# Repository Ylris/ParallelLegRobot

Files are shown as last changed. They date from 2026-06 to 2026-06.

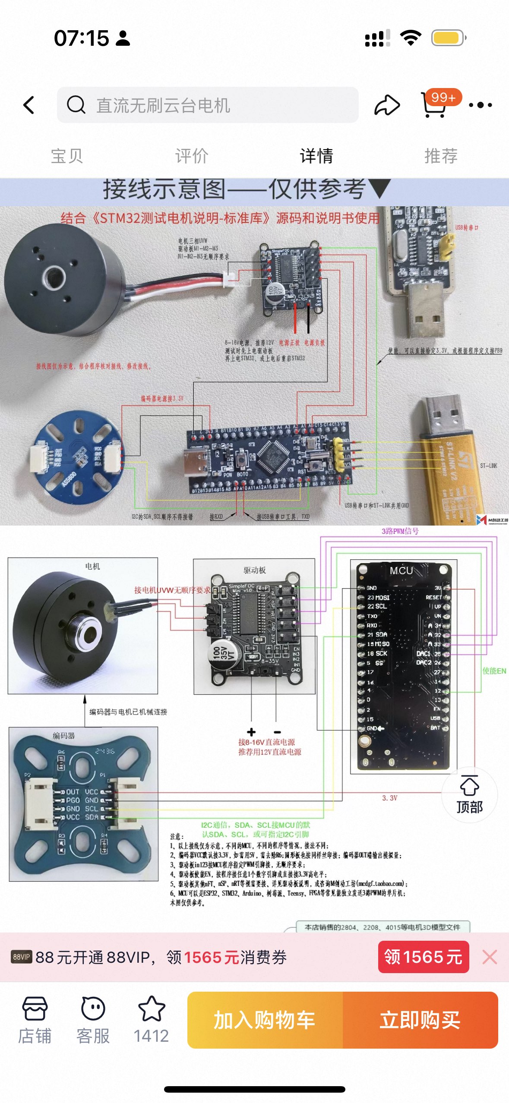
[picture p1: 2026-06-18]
docs/3ED894091CCDE273470E72D72C9ACDA5.jpg

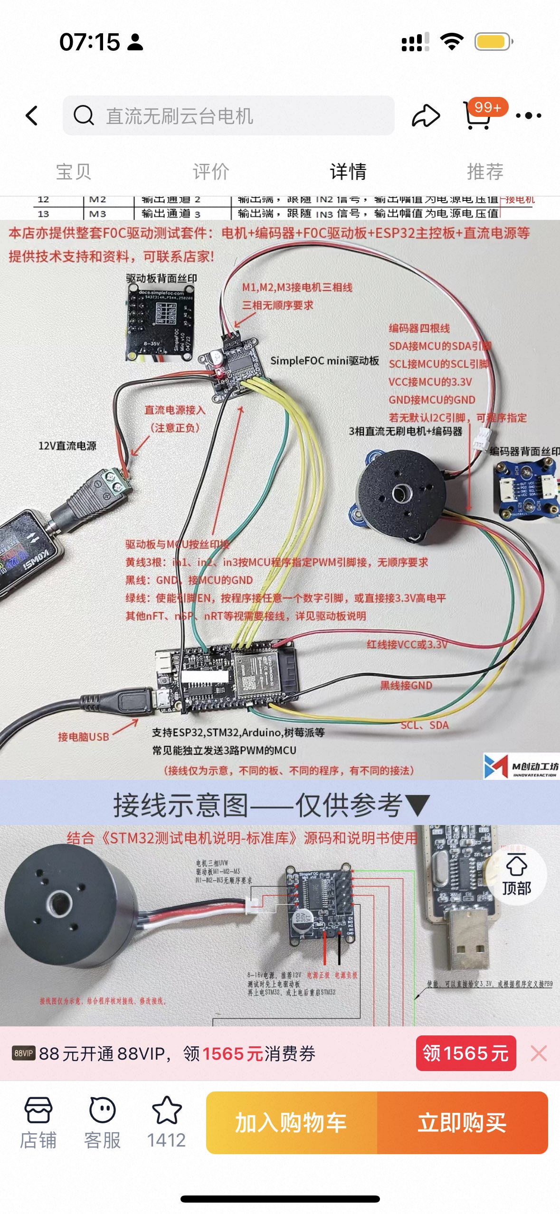
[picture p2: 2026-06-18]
docs/41C43278776642E51C22B02BB5EA1A30.jpg

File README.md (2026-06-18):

# ESP32-C3 轮腿 CAN 主控 + IMU 姿态反馈

这是一个基于 ESP32-C3 与 PlatformIO 搭建的 **轮腿机器人主控板** 项目。主控通过 CAN 总线连接电机驱动器，并接入 MPU6050 IMU，用于轮腿/并联腿机构的运动控制与姿态反馈。

并联腿（如经典的五杆闭链机构，Five-bar linkage）由于其电机（舵机）都可以安装在靠近身体的根部，具有极低的腿部惯量，非常适合制作高性能的双足或四足跑跳机器人。

此外，本项目集成了 **MPU6050 IMU** 传感器，通过互补滤波算法计算出机身姿态（Pitch），实现了闭环姿态反馈调节（自平衡模式）。

---

## 1. 机构几何模型与原理

该并联腿使用五杆闭链机构，其坐标系与结构定义如下：

```
       [ 机器人身体 (y = 0) ]
     A1 (-d, 0)      A2 (d, 0)   <-- 左右两个主动无刷电机轴心
       \            /
   L1   \          /   L1        <-- 主动臂 (Link 1)
         \        /
         B1      B2              <-- 肘部转轴 (无源关节)
         /        \
   L2   /          \   L2        <-- 从动臂 (Link 2)
       /            \
       \            /
        \          /
         \        /
          \      /
           \    /
            \  /
             \/
             P (x, y)            <-- 足端电机 (Foot End-effector)
```

- **原点 (0, 0)**: 左右舵机旋转轴心连线的中点。
- **$A_1, A_2$**: 左右舵机轴心位置，坐标分别为 $(-d, 0)$ 和 $(d, 0)$。
- **$L_1$**: 主动臂长度 (从舵机臂到肘部)。
- **$L_2$**: 从动臂长度 (从肘部到足端)。
- **$B_1, B_2$**: 左右肘部关节坐标。
- **$P(x, y)$**: 足端坐标。

### 逆运动学 (Inverse Kinematics, IK)
通过给定的足端目标位置 $P(x, y)$，反算出左右舵机的目标控制角度 $\theta_1$ 和 $\theta_2$。
- 利用余弦定理和极坐标变换求解三角形 $A_1B_1P$ 和 $A_2B_2P$。
- 设定肘部向外弯曲（肘朝外，Outer-bending），以获得最大的工作空间并避免杆件相撞。

### 顺运动学 (Forward Kinematics, FK)
通过给定的左右舵机角度 $\theta_1$ 和 $\theta_2$，计算出当前足端所处的坐标 $P(x, y)$。
- 求解两圆相交问题：圆心分别为 $B_1$ 和 $B_2$，半径均为 $L_2$ 的两个圆的交点中，取 $Y$ 值较小的交点（向下延伸的点）。

---

## 2. 硬件方案与引脚分配 (ESP32-C3 + CAN)

当前原理图使用 **ESP32-C3** 作为主控，通过片内 **TWAI/CAN 控制器** 输出 `CAN_TX/CAN_RX`，再由外置 **TJA1050T CAN 收发器** 转换为 CANH/CANL 差分总线。MPU6050 通过 I2C 接入，USB Type-C 用于 5V 供电、烧录和串口调试。

### 2.1 主控引脚分配

| 功能 | ESP32-C3 引脚 | 原理图网络名 | 逻辑电平 | 连接对象 | 备注 |
| :--- | :--- | :--- | :--- | :--- | :--- |
| I2C SCL | `GPIO3` | `I2C_SCL` | 3.3V | MPU6050/F103/轮编码器 `SCL` | 当前代码 `include/LegConfig.h` 使用 GPIO3 |
| I2C SDA | `GPIO4` | `I2C_SDA` | 3.3V | MPU6050/F103/轮编码器 `SDA` | 当前代码 `include/LegConfig.h` 使用 GPIO4 |
| CAN TX | `GPIO6` | `CAN_TX` | 3.3V | TJA1050T `TXD` | ESP32-C3 TWAI 发送脚 |
| CAN RX | `GPIO7` | `CAN_RX` | 3.3V 输入 | TJA1050T `RXD` | 需要注意 TJA1050T 的 5V 输出电平 |
| BOOT | `GPIO9` | `BOOT` | 3.3V | 下载按键到 GND | 进入下载模式使用 |
| LED | `GPIO10` | `LED` | 3.3V | `R5 + LED1` | 状态指示灯 |
| ADC | `GPIO0` | `ADC` | 3.3V | 电压采样分压 | `R7/R8` 分压后进入 ADC |
| USB D+ / D- | `GPIO19/GPIO18` | `USB+` / `USB-` | USB | Type-C 座 | 烧录、调试串口 |
| EN | `EN` | `EN` | 3.3V | 复位按键 | `R1=10k` 上拉到 3V3 |

> **[!WARNING]**
> * ESP32-C3 的 GPIO 是 3.3V 逻辑，不建议直接承受 5V 输入。TJA1050T 使用 5V 供电，`RXD` 高电平可能接近 5V，因此 `TJA1050T RXD -> ESP32-C3 CAN_RX(GPIO7)` 之间建议加电平转换，或改用带 3.3V 逻辑接口的 CAN 收发器。
> * 更推荐的 3.3V 方案是 `SN65HVD230/VP230`、`TCAN332/TCAN337`，或带 `VIO=3.3V` 的 `MCP2562`。如果继续使用 TJA1050T，至少要确认 CAN_RX 输入不会超过 ESP32-C3 允许范围。
> * ESP32-C3 原生 USB 通常使用 `GPIO19=USB_D+`、`GPIO18=USB_D-`。画板前请再核对 `USB+`、`USB-` 是否分别接到正确引脚。

---

## 2.2 CAN 收发器与总线接线

TJA1050T 在本方案中只负责物理层收发，CAN 协议解析由 ESP32-C3 的 TWAI 控制器和 YYT MiniOdrive 上的 STM32 FDCAN 外设完成，不需要 MCP2515。

| TJA1050T 引脚 | 原理图连接 | 说明 |
| :--- | :--- | :--- |
| `TXD` | `CAN_TX` / ESP32-C3 `GPIO6` | 主控发送到收发器 |
| `RXD` | `CAN_RX` / ESP32-C3 `GPIO7` | 收发器输出到主控，建议做 5V 到 3.3V 电平转换 |
| `VCC` | `5V0` | TJA1050T 供电为 5V |
| `GND` | `GND` | 与 ESP32-C3、电机驱动器共地 |
| `S` | `GND` | 高速正常模式 |
| `CANH` | CAN 连接器 `CANH` | CAN 总线高线 |
| `CANL` | CAN 连接器 `CANL` | CAN 总线低线 |
| `VREF` | 悬空 | 当前方案未使用 |

总线两端各放一个 `120R` 终端电阻即可。原理图中的 `R6=120R` 已经跨接在 CANH/CANL 上，如果这块板位于总线中间，应取消或改成可选跳帽；如果这块板位于总线端点，可以保留。

### 2.3 电源与外设

* **Type-C 供电**：USB Type-C 的 `VBUS` 接入 `5V0`，用于给 5V 轨和后级 3.3V LDO 供电。
* **3.3V 供电**：`SPX3819-3.3` 从 `5V0` 生成 `3V3`，供 ESP32-C3 和 MPU6050 使用。
* **5V 供电**：TJA1050T 接 `5V0`。电机动力电源不要从 ESP32-C3 板上取，应由独立电池或电源给 YYT 驱动器供电。
* **MPU6050**：`VDD` 接 `3V3`，`GND/EP` 接地，I2C 上拉到 3V3。
* **复位与下载**：`EN` 通过 10k 上拉到 3V3，复位按键拉低；`BOOT(GPIO9)` 下载按键拉低。

### 2.4 下位机配置

腿电机驱动板使用 STM32G431，工程目录 `DriveFirmware/` 中已经包含 FDCAN 相关代码：

* `DriveFirmware/Core/Src/fdcan.c`：FDCAN1 初始化，Classic CAN，当前位时序约 1 Mbps。
* `DriveFirmware/Core/Src/can_bridge.c`：CAN 命令解析、电机电压控制和状态回传。

每块电机驱动板需要设置唯一的 `DRIVE_ID`。当前协议按 ID 分组：

当前实物 ID 以侧视图/图面坐标为准：

| 侧视图位置 | 电机 ID | 用途 |
| :--- | :--- | :--- |
| 左上 | `1` | 左侧上方腿关节电机 |
| 左下 | `2` | 左侧下方腿关节电机 |
| 右上 | `5` | 右侧上方腿关节电机 |
| 右下 | `6` | 右侧下方腿关节电机 |
| 左腿轮电机 | `3` | 左轮驱动电机 |
| 右腿轮电机 | `4` | 右轮驱动电机 |

电机组装好后，需要根据 `闭环参数调试.docx` 校准 AS5600 或 MT6816 磁编码器，并确认零点参数已经保存到驱动板。

### 2.5 每个执行器驱动器怎么连接、干什么

当前机器人把执行器分成两类：

* **四个腿关节执行器**：YYT MiniOdrive 驱动板，走 CAN 总线，由 ESP32-C3 主控直接发送电压命令。
* **两个轮电机执行器**：SimpleFOC 驱动板，当前方案由 STM32F103C8T6 最小系统板输出 PWM/方向信号，ESP32-C3 通过 I2C 给 F103 下发左右轮 PWM。

#### 腿关节 YYT MiniOdrive 驱动器

四块 YYT 都并联在同一条 CAN 总线上。每块板需要三类连接：动力电源、CAN 通信、调试烧录。

| 驱动器 | 安装位置 | 系统作用 | CAN 命令位置 | CAN 反馈 ID | 固件文件 |
| :--- | :--- | :--- | :--- | :--- | :--- |
| `ID1` | 图面/侧视图左上腿关节 | 左腿上关节执行器，改变左腿主动臂角度 | 标准帧 `0x100`，payload 字节 `0..1` | `0x101` | `DriveFirmware/firmware_ids/turing_CBU6_id1.hex` |
| `ID2` | 图面/侧视图左下腿关节 | 左腿下关节执行器，改变左腿另一主动臂角度 | 标准帧 `0x100`，payload 字节 `2..3` | `0x102` | `DriveFirmware/firmware_ids/turing_CBU6_id2.hex` |
| `ID5` | 图面/侧视图右上腿关节 | 右腿上关节执行器，改变右腿主动臂角度 | 标准帧 `0x200`，payload 字节 `0..1` | `0x105` | `DriveFirmware/firmware_ids/turing_CBU6_id5.hex` |
| `ID6` | 图面/侧视图右下腿关节 | 右腿下关节执行器，改变右腿另一主动臂角度 | 标准帧 `0x200`，payload 字节 `2..3` | `0x106` | `DriveFirmware/firmware_ids/turing_CBU6_id6.hex` |

YYT 驱动器的 CAN 连接：

| 自制 ESP32-C3 主控板外部接口 | YYT MiniOdrive `CN2` | 作用 |
| :--- | :--- | :--- |
| `CAN+` / `CANH` | `CN2 pin 2 CANH` | CAN 差分高线 |
| `CAN-` / `CANL` | `CN2 pin 1 CANL` | CAN 差分低线 |
| `GND` | YYT `GND` 或电源负极 | 共地，必须接 |

四个 `ID1/ID2/ID5/ID6` 与 ESP32-C3 的通信关系：

```text
ESP32-C3 主控芯片
  GPIO6 = CAN_TX  ---->  TJA1050T TXD
  GPIO7 = CAN_RX  <----  TJA1050T RXD

TJA1050T CAN 收发器
  CANH/CAN+  <====================>  四块 YYT 的 CANH 并联
  CANL/CAN-  <====================>  四块 YYT 的 CANL 并联
  GND        <====================>  四块 YYT / 电源负极共地

同一条 CAN 总线上挂着：
  YYT ID1, YYT ID2, YYT ID5, YYT ID6
```

这里要分清楚三层信号：

| 层级 | 信号名 | 在哪里 | 说明 |
| :--- | :--- | :--- | :--- |
| ESP32 逻辑层 | `CAN_TX=GPIO6`、`CAN_RX=GPIO7` | ESP32-C3 到 TJA1050T 之间 | 这是 3.3V 逻辑信号，不直接接 YYT |
| CAN 物理层 | `CANH/CANL` 或 `CAN+/CAN-` | TJA1050T 到 YYT 总线之间 | 这是差分总线，四块 YYT 并联在同一对线上 |
| 协议层 | 标准 CAN ID `0x100/0x200/0x101...` | CAN 数据帧里 | 用帧 ID 和 payload 字节区分具体电机 |

ESP32-C3 主控发送给四个腿电机的命令帧：

| CAN 标准帧 ID | payload 字节 | 对应驱动器 | 单位 | 说明 |
| :--- | :--- | :--- | :--- | :--- |
| `0x100` | `data[0..1]` | `ID1` | `int16_t` mV，小端 | 左上腿关节电压命令 |
| `0x100` | `data[2..3]` | `ID2` | `int16_t` mV，小端 | 左下腿关节电压命令 |
| `0x100` | `data[4..5]` | `ID3` | `int16_t` mV，小端 | 预留给左轮/低 ID 第 3 路；当前腿联调不用 |
| `0x100` | `data[6..7]` | `ID4` | `int16_t` mV，小端 | 预留给右轮/低 ID 第 4 路；当前腿联调不用 |
| `0x200` | `data[0..1]` | `ID5` | `int16_t` mV，小端 | 右上腿关节电压命令 |
| `0x200` | `data[2..3]` | `ID6` | `int16_t` mV，小端 | 右下腿关节电压命令 |
| `0x200` | `data[4..5]` | `ID7` | `int16_t` mV，小端 | 预留 |
| `0x200` | `data[6..7]` | `ID8` | `int16_t` mV，小端 | 预留 |

举例：如果主控要给 `ID1=+1000 mV`、`ID2=-500 mV`，就发送标准帧 `0x100`，8 字节 payload 大致是：

```text
data[0..1] = +1000 的 int16 小端
data[2..3] = -500 的 int16 小端
data[4..5] = 0
data[6..7] = 0
```

每块 YYT 固件里都有自己的 `DRIVE_ID`。收到 CAN 帧后，YYT 会这样判断：

| YYT 固件 ID | 会监听的命令帧 | 从 payload 取哪两个字节 |
| :--- | :--- | :--- |
| `DRIVE_ID=1` | `0x100` | `data[0..1]` |
| `DRIVE_ID=2` | `0x100` | `data[2..3]` |
| `DRIVE_ID=5` | `0x200` | `data[0..1]` |
| `DRIVE_ID=6` | `0x200` | `data[2..3]` |

也就是说，四个电机不是四根单独通信线，而是 **同一条 CAN 总线 + 不同 ID/不同 payload 位置**。ESP32 同时发两帧，四块 YYT 各自取属于自己的那一格命令。

四块 YYT 回传给 ESP32-C3 的反馈帧：

| 驱动器 | 反馈 CAN 标准帧 ID | payload | ESP32 用途 |
| :--- | :--- | :--- | :--- |
| `ID1` | `0x101` | `data[0..3]` 角度 mrad，`data[4..5]` 速度 `rpm x10` | 判断 ID1 online，计算左上关节角度 |
| `ID2` | `0x102` | 同上 | 判断 ID2 online，计算左下关节角度 |
| `ID5` | `0x105` | 同上 | 判断 ID5 online，计算右上关节角度 |
| `ID6` | `0x106` | 同上 | 判断 ID6 online，计算右下关节角度 |

ESP32-C3 主控的 `status` 命令里看到：

```text
online: ID1=yes ID2=yes ID5=yes ID6=yes
```

就说明 ESP32 已经在同一条 CAN 总线上收到了四块 YYT 的反馈帧。某个 ID 显示 `no/offline`，通常表示这块驱动器没供电、CANH/CANL/GND 接触问题、对应 ID 固件没烧对，或者动作时驱动器重启/掉线。

YYT 动力电源连接：

| 电源线 | 接到哪里 | 作用和注意 |
| :--- | :--- | :--- |
| 电源正极 | YYT 主电源正极 / 电机电源输入 | 给功率级和电机供电，不能从 ESP32 板取 |
| 电源负极 | YYT 主电源负极 / GND | 必须与 ESP32 主控 GND 共地 |
| 三相线 | YYT 三相输出到电机三相线 | 已焊好的三相线不需要在普通 CAN 联调时拔掉 |

YYT 的 ST-Link/SWD 只用于烧录和调试，正常跑机器人时不接：

| YYT `U66` | ST-Link | 作用 |
| :--- | :--- | :--- |
| `pin 1 GND` | `GND` | 调试器地 |
| `pin 2 SWCLK` | `SWCLK/CLK` | SWD 时钟 |
| `pin 3 SWDIO` | `SWDIO/DIO` | SWD 数据 |
| `pin 4 VCC` | `3.3V/VTref` | 目标板参考电压 |
| `pin 5/6` | 不接 | 空脚或固定脚 |

YYT CAN 固件的行为：

* ESP32 每个控制周期发送 `0x100` 和 `0x200` 两帧，把四个腿关节的电压命令发给驱动器。
* YYT 收到属于自己 ID 的命令后进入电压控制模式，单位是 mV。
* YYT 超过约 `100 ms` 没收到新 CAN 命令，会自动把输出清零并退出电压控制。
* 每块 YYT 回传 `0x100 + ID`，包含当前磁编码器角度和速度，ESP32 用这些反馈判断 online、关节角度和保持误差。

#### 轮电机 SimpleFOC 驱动器

轮电机采用两块 3-PWM 接口的 SimpleFOC 无刷电机驱动板。其执行链路是：

```text
ESP32-C3 主控
  -> I2C 总线 GPIO3(SCL) / GPIO4(SDA)
  -> STM32F103C8T6 轮电机 6-PWM 协处理器, I2C 地址 0x12
  -> 6路三相PWM + 2路使能信号
  -> 两块 SimpleFOC 轮电机驱动板 (3-PWM 模式)
  -> 左右无刷轮电机
```

STM32F103C8T6 到 SimpleFOC 的 6-PWM 引脚分配定义：

| F103 引脚 | 定时器通道 | 接到 SimpleFOC | 作用 |
| :--- | :--- | :--- | :--- |
| `PA0` | TIM2_CH1 | 左轮 SimpleFOC `IN1` | 左轮 U 相驱动输入 |
| `PA1` | TIM2_CH2 | 左轮 SimpleFOC `IN2` | 左轮 V 相驱动输入 |
| `PA2` | TIM2_CH3 | 左轮 SimpleFOC `IN3` | 左轮 W 相驱动输入 |
| `PA4` | GPIO Out | 左轮 SimpleFOC `EN` | 左轮使能控制信号 |
| `PA8` | TIM1_CH1 | 右轮 SimpleFOC `IN1` | 右轮 U 相驱动输入 |
| `PA9` | TIM1_CH2 | 右轮 SimpleFOC `IN2` | 右轮 V 相驱动输入 |
| `PA10`| TIM1_CH3 | 右轮 SimpleFOC `IN3` | 右轮 W 相驱动输入 |
| `PA5` | GPIO Out | 右轮 SimpleFOC `EN` | 右轮使能控制信号 |
| `PB6` | I2C1_SCL | ESP32 I2C `SCL` 总线 | F103 作为 I2C 从机 |
| `PB7` | I2C1_SDA | ESP32 I2C `SDA` 总线 | F103 作为 I2C 从机 |
| `GND` | - | ESP32 GND / SimpleFOC GND | 必须共地 |

轮磁编码器也挂在同一条 ESP32 I2C 总线上：

| 设备 | I2C 地址 | 接线 | 作用 |
| :--- | :--- | :--- | :--- |
| MPU6050 | `0x68` | `SCL=GPIO3`, `SDA=GPIO4` | 机身姿态 |
| STM32F103 轮 PWM 协处理器 | `0x12` | `SCL=GPIO3`, `SDA=GPIO4` | 接收左右轮 PWM 控制量（STM32 不做闭环，仅输出 PWM/DIR 驱动 SimpleFOC） |
| 左轮磁编码器 | `0x36` | `SCL=GPIO3`, `SDA=GPIO4` | 左轮位置反馈（由 ESP32 直接读取） |
| 右轮磁编码器 | `0x38` | `SCL=GPIO3`, `SDA=GPIO4` | 右轮位置反馈（由 ESP32 直接读取） |

### 2.6 当前软件适配状态

`DriveFirmware/` 下位机固件已经是 CAN 接收方案；根目录 `src/main.cpp` 当前是现场 12V 测试用 CAN 主控，默认使用 `CAN_TX=GPIO6`、`CAN_RX=GPIO7`。当前测试构建里 `armed=true`、`YYT_ALLOW_UNTESTED_DIRS=1`，但启动命令仍为 0 mV；恢复保守 bring-up 时应改回上电 `disarmed`。

截至 2026-06-18 的现场状态：

* 四个腿电机 ID 为 `1/2/5/6`，均能通过 CAN 在线反馈。
* 侧视图/图面坐标：左上 `ID1`、左下 `ID2`、右上 `ID5`、右下 `ID6`；左腿轮电机 `ID3`，右腿轮电机 `ID4`。
* 机械零点已写入 `config/leg_calibration.json`，主控中也固化了对应零点。
* YYT 预编译固件在 `DriveFirmware/firmware_ids/`，文件名里带 `_6v` 的是历史命名；当前主控按 12V 标准电机测试，命令上限配置为 `+/-12000 mV`。
* 主控支持串口命令 `status`、`can`、`imu`、`imustream on/off`、`arm`、`test`、`confirm_dirs`、`stand`、`height`、`holdoff`、`stop`、`disarm`、`zero6`、`zero <id>`（驱动侧位置保持）、`zero`（主控位置保持）、`wheelarm`、`wheeldisarm`、`wheelpwm <l> <r>`、`wheelstream <on|off>`。
* 轮电机方案使用同一条 I2C 总线：ESP32-C3 `SCL=GPIO3`、`SDA=GPIO4`，连接 MPU6050、STM32F103 PWM 协处理器和两个轮磁编码器（左轮 `0x36`，右轮 `0x38`）；细节见 `docs/wheel_motor_i2c_plan.md`。
* 最近现场确认 `ID6` 能在 12V 测试下动作，方向以负命令朝机械零点方向为准；四电机零位闭环保持仍需继续现场验证。

---

## 3. 项目结构说明

本项目的目录结构符合标准的 PlatformIO 规范：

```
WheelLegCANController/
├── include/
│   ├── LegConfig.h         # 物理参数、I2C引脚、零偏校准及工作空间限幅
│   ├── LegKinematics.h     # 顺/逆运动学求解器类定义
│   └── ImuManager.h        # IMU读取和互补滤波类定义
├── src/
│   ├── LegKinematics.cpp   # 运动学数学计算实现
│   ├── ImuManager.cpp      # I2C总线扫描、MPU6050初始化及姿态滤波算法
│   └── main.cpp            # ESP32-C3 初始化、指令解析与轨迹控制主程序
├── platformio.ini          # PlatformIO 项目编译配置文件
└── README.md               # 本说明文件
```

---

## 4. IMU 姿态解算与自平衡控制

1. **I2C 设备扫描**: 
   启动时，主机会自动扫描 I2C 总线并打印所有在线设备。这方便了用户排查接线故障，确保 IMU（如 MPU6050 默认地址 `0x68`）正确挂载。
2. **互补滤波姿态估计 (Complementary Filter)**:
   - 融合陀螺仪的积分角度与加速度计得到的重力夹角。
   - 表达式：$Angle = 0.96 \times (Angle + GyroRate \times dt) + 0.04 \times AccelAngle$。
   - 具有极高的稳定性和响应速度，有效滤除高频电机振动干扰。
3. **姿态平衡环控制 (MODE_BALANCE)**:
   - 闭环控制算法：机身向前倾斜（$Pitch > 0$）时，控制脚掌向前偏移以维持中心平衡；
   - 控制率：$X_{\text{compensate}} = Pitch \times K_p$ ($K_p = -1.2 \text{mm/deg}$)。
   - 可在开发板倾斜时实时驱动舵机运动以使足端朝反方向平移支撑。

---

## 5. 串口指令控制与交互

烧录程序后，通过串口助手（如 PlatformIO Serial Monitor，波特率 `115200`）连接机器人，可发送以下指令进行交互：

- `standby`: 机器人腿部将收回并静态悬停在中位 `(0, -100)` mm 处（开机默认模式）。
- `balance`: 开启 IMU 自平衡反馈（当倾斜机身时，机器人会根据 MPU6050 采集到的 Pitch 角度反向移动以维持平衡）。
- `X Y`: 手动控制足端移动到指定坐标（例如输入 `10 -90`，回车后足端会平滑移动到该位置。若输入的值超出了可达工作空间，终端会输出警告且保持安全限幅）。

---

## 6. 编译与烧录

使用 PlatformIO 命令行在项目根目录下进行编译与烧录：

```bash
# 1. 编译项目
pio run

# 2. 烧录到 ESP32-C3 核心板
pio run --target upload
```

---

## 7. 系统通信架构与协议规范

系统主要由三部分组成：**ESP32-C3（主控）**、**YYT MiniOdrive（电机驱动器）** 和 **PioPulse（PC 端 TUI 可视化软件）**。当前硬件方案以 CAN 总线连接主控和电机驱动器，USB 串口用于 PC 调试与姿态可视化。

### ① ESP32-C3 $\leftrightarrow$ YYT MiniOdrive 电机驱动器

* **物理连接**：ESP32-C3 `GPIO6/GPIO7` 作为 TWAI `TX/RX`，经过 TJA1050T 转换为 CANH/CANL，再连接到所有 YYT MiniOdrive 驱动板。
* **总线类型**：Classic CAN，非 CAN FD。
* **建议波特率**：`1 Mbps`，需要与 `DriveFirmware/Core/Src/fdcan.c` 的 FDCAN 位时序保持一致。
* **命令帧**：主控周期性发送标准帧 `0x100` 和 `0x200`，每帧 8 字节，每两个字节对应一个电机的命令值。

命令帧 payload 使用小端序 `int16_t`，单位为 mV：

| 字节 | 含义 |
| :--- | :--- |
| `0..1` | 分组内第 1 个电机电压命令 |
| `2..3` | 分组内第 2 个电机电压命令 |
| `4..5` | 分组内第 3 个电机电压命令 |
| `6..7` | 分组内第 4 个电机电压命令 |

主控当前按 12V 电机配置，测试/保持命令上限为 `+/-12000 mV`。下位机在收到有效命令后进入电压控制模式；超过 `100 ms` 没有收到新命令时，下位机会清零命令并退出该模式。

驱动器反馈帧使用标准 ID `0x100 + DRIVE_ID`，8 字节小端序：

| 字节 | 类型 | 含义 |
| :--- | :--- | :--- |
| `0..3` | `int32_t` | 电机角度，单位 mrad |
| `4..5` | `int16_t` | 电机速度，单位 `rpm x10` |
| `6..7` | `int16_t` | 预留 |

### ② ESP32-C3 $\leftrightarrow$ PioPulse 终端可视化
* **物理连接**：ESP32-C3 的 Native USB/调试串口（`GPIO 18/19`）通过 USB 线连接至 PC 电脑。
* **串口配置**：波特率 **`115200`**，流控无。
* **TUI 帧传输协议 (FireWater)**：
  * **数据格式**：以 `\n`（换行符）结尾的逗号分割 ASCII 字符串。
  * **输出示例**：`imu:pitch_val,roll_val,yaw_val,0.0,0.0,0.0\n` （前三位为 MPU6050 经过互补滤波后的 Pitch, Roll, Yaw 姿态度数；后三位为平移占位符，PioPulse 内置的 3D 立方体控件将会直接读取这 6 个通道渲染出实时 3D 姿态）。

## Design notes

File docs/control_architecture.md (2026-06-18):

# 主控控制结构说明

本文档说明当前 `ParallelLegRobot` 主控程序如何参考本地 `foc-wheel-legged-robot`，以及哪些能力已经实现、哪些能力要等轮电机和整车条件满足后再做。

## 参考仓库的可用思路

参考文件：

- `foc-wheel-legged-robot/esp32-controller/software/src/main.cpp`
- `foc-wheel-legged-robot/esp32-controller/software/src/leg_pos.c`
- `foc-wheel-legged-robot/esp32-controller/software/src/leg_spd.c`
- `foc-wheel-legged-robot/esp32-controller/software/src/leg_conv.c`
- `foc-wheel-legged-robot/esp32-controller/software/src/lqr_k.c`

参考仓库的主程序是完整轮腿平衡车结构，大致分为：

- 电机层：保存角度、速度、零点、方向、目标电压。
- CAN 层：周期发送 0x100/0x200 电压命令，接收 0x101/0x102/... 反馈。
- 腿部状态层：把关节角度换算为腿长、腿角、腿速。
- 控制层：根据 IMU、轮速、腿长等状态计算关节和轮电机输出。
- 安全层：`robotArmed` 默认关闭，上电不允许直接出力。

当前现场 bring-up 仍先以四个腿关节电机架空调通为主。轮电机硬件编号已经确定为左腿轮电机 ID3、右腿轮电机 ID4，但整车站立和平衡闭环还需要等轮电机、IMU、轮速和姿态状态都接入后再验证。

## 当前默认主程序

默认构建目标是 `platformio.ini` 里的 `[env:esp32-c3-devkitm-1]`。

主程序文件：

- `src/main.cpp`

编译时关键参数：

- `YYT_CAN_RX_PIN=7`
- `YYT_CAN_TX_PIN=6`
- `YYT_SAFE_MV_LIMIT=12000`
- `YYT_MIN_TEST_MV=6000`
- `YYT_HOLD_MV_LIMIT=12000`
- `ARDUINO_USB_CDC_ON_BOOT=1`

CAN 线序：

- 自制主控板 CAN+ 接 YYT CANH。
- 自制主控板 CAN- 接 YYT CANL。
- ESP32C3 逻辑侧 CAN_RX 是 GPIO7，CAN_TX 是 GPIO6。

## 电机 ID 和零点

当前电机 ID 以侧视图/图面坐标为准：

- 图面左上腿关节：ID1
- 图面左下腿关节：ID2
- 图面右上腿关节：ID5
- 图面右下腿关节：ID6
- 左腿轮电机：ID3
- 右腿轮电机：ID4

零点来自：

- `config/leg_calibration.json`

固件中对应常量在 `src/main.cpp` 的 `kMotors`：

- ID1 zero = `4.860`
- ID2 zero = `5.553`
- ID5 zero = `0.161`
- ID6 zero = `1.991`, drive_sign = `-1`

反馈角度处理逻辑：

```text
raw angle mrad -> angle_rad -> normalize(angle_rad - zero) * sign -> q
```

其中 `q` 是主控使用的归一化关节角。运行时可以用 `sign <id> <1|-1>` 或 `invert <id>` 临时调整方向；重启后恢复固件默认方向。

## CAN 协议

YYT 驱动板反馈：

- `0x101` -> ID1
- `0x102` -> ID2
- `0x105` -> ID5
- `0x106` -> ID6

反馈数据：

- bytes 0..3：`int32 angle_mrad`
- bytes 4..5：`int16 speed_rpm_x10`

主控发送：

- `0x100` 控制 ID1..ID4
- `0x200` 控制 ID5..ID8

每个电机一个 `int16 mV` 槽位，小端序。

特殊哨兵值：

- `+2345 mV` 或 `-2345 mV`：YYT 驱动板本地零点位置保持。当前用于 ID6，驱动固件把目标设为 `DRIVE_ZERO_RAD=1.991`，接近后进入 PI 位置保持。
- `+4321 mV` 或 `-4321 mV`：YYT 驱动板本地低速开环旋转测试。

## 安全状态机

当前现场测试固件默认：

- `armed = true`
- `height_hold_enabled = false`
- 所有命令为 `0 mV`

如果后续恢复保守 bring-up 配置，应改回上电 `armed = false`，必须输入：

```text
arm
```

才允许输出非零电压。

单关节点动：

```text
test <id> <mv> <ms>
```

限制：

- 只允许 ID1/2/5/6。
- 持续时间限制为 20 到 300 ms。
- 非零点动命令低于 `YYT_MIN_TEST_MV` 时会提升到 6000 mV，最高受 `YYT_SAFE_MV_LIMIT=12000` 限制。
- 点动结束自动清零输出。
- 点动后打印 `q_before`、`q_after`、`dq`。

方向确认：

- 每个 ID 必须至少成功执行过一次 `test`。
- `confirm_dirs` 只有在 ID1/2/5/6 都是 `tested=yes` 后才会通过。
- 使用 `sign` 或 `invert` 后，该 ID 的 `tested` 会回到 `no`。

高度保持：

```text
height 100
```

限制：

- 必须先 `arm`。
- 必须先 `confirm_dirs`。
- 四个腿电机必须在线。
- 高度范围暂时限制为 80 到 120 mm。
- 输出受 `YYT_HOLD_MV_LIMIT` 限制。
- 目标角度按斜坡慢慢接近，避免突然动作。

自动停止条件：

- `disarm` 或 `stop`
- 任一腿电机离线
- 关节超过软限位
- CAN 发送失败
- CAN 总线错误
- TWAI 状态不是 `running`

ID6 专用零点保持：

```text
zero6
```

限制：

- 必须先在线看到 ID6。
- 主控持续给 ID6 槽位发送 `2345 mV` 哨兵值。
- 位置闭环在 ID6 驱动板本地执行，不要求其它腿电机在线。
- `stop`、`holdoff` 或 `disarm` 会清零输出并退出保持。

## 当前已经实现的目标

当前软件已经实现：

- 四个腿电机 CAN 反馈读取。
- 零点归一和方向修正。
- 默认上电不动作。
- 串口 `arm/disarm/stop`。
- 单关节点动和 `dq` 输出。
- 四关节 tested 门槛。
- 指定高度保持框架。
- CAN 状态查询。
- 点动日志、高度保持日志、日志分析脚本。

历史 bring-up 记录曾通过只读串口验证；当前硬件状态以实时 `status` 输出为准：

- ID1/2/5/6 能在线。
- 当前现场测试构建默认 `armed=yes`。
- 默认 `hold=off`。
- 默认命令 `0 mV`。

## 当前还必须现场验证的目标

必须由现场测试证明：

- 四个关节点动时电流不异常。
- 四个关节 ID 和机械方向正确。
- `height 100` 时两条腿缓慢移动到目标高度。
- 高度保持期间不撞限位、不明显抖动。
- 高度保持日志中没有 CAN 掉线、发送失败、电机离线。

推荐现场顺序：

```sh
python3 tools/leg_test_sequence.py --port /dev/cu.usbmodem1301
python3 tools/height_hold_monitor.py --port /dev/cu.usbmodem1301 --height 100 --duration 8
python3 tools/analyze_bringup_logs.py --leg-log logs/leg_test_时间.txt --height-log logs/height_hold_时间.txt
```

只有日志分析通过，并且现场观察确认电流、限位、抖动都正常，当前 goal 才能算完成。

## 后续扩展路径

轮电机闭环未接入前，不做真正站立平衡。

后续加回轮电机后，再按这个顺序扩展：

- 接入轮电机 ID3/ID4 的零点、方向和速度反馈。
- 接入 MPU6050 姿态。
- 引入腿长、腿角、腿速状态。
- 引入轮速和车体速度估计。
- 再参考 `lqr_k.c` 和原主控结构做 LQR 平衡。

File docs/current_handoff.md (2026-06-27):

# Current Handoff

Last updated: 2026-06-28 CST (Asia/Shanghai)

> [!IMPORTANT]
> 当前阶段先把 YYT 腿电机调成可靠执行器。先不要调轮电机、新 IMU、平衡、站立高度闭环。

## 当前目标

把 ID1/ID2/ID5/ID6 四块 YYT MiniOdrive 都统一成：

- 上电做 sweep-align 电角度对齐
- 通过 CAN 稳定 online 并回传角度
- 收到 ESP32 的 mV 电压命令后平滑出力
- 不使用 YYT 本地位置保持作为通用默认行为
- 默认 0 mV，不主动动作；ESP32 输入 `arm` 后才允许点动

ESP32 仍然是上位机，负责之后的腿高、姿态、整车控制；YYT 先只做底层 FOC/电压执行器。

## 当前现场状态

- ST-Link 当前按用户描述接在 ID2。
- 已重新编译并烧录 ID2 的 sweep-align CAN 电压执行器固件。
- 烧录命令已执行成功，OpenOCD 输出 `Verified OK`。
- 随后固件增加了 sweep-align 后的 32 次圆周平均采样，用于降低电角度零点读数抖动；此平均采样版已编译通过，但尚未烧录到板子。
- ESP32 主控程序已编译通过。
- macOS 当前没有识别到 ESP32 USB 串口；扫描只看到 `/dev/cu.Bluetooth-Incoming-Port` 和 `/dev/cu.debug-console`。
- 因为没有 ESP32 串口，暂时还不能发 `status`、`arm`、`test` 来验证 CAN 和 ID2 正负点动。
- 最新一次 OpenOCD 探测失败为 `Error: open failed`，随后 USB 设备树也没有看到 `STM32 STLink`，需要重新插好 ST-Link USB 后再烧录。

## 立即下一步

1. 插好 ESP32 主控板 Type-C USB 线。
2. 让 macOS 出现类似 `/dev/cu.usbmodem...` 或 `/dev/cu.usbserial...` 的端口。
3. 给 YYT 板上 12V 动力电源，限流保守，电机保持自由转动或架空。
4. 等待 3 秒左右，让 ID2 完成 sweep-align。
5. 查询状态：

```sh
cd /Users/ylris/轮腿/ParallelLegRobot
python3 -B tools/read_status_safe.py --command status
python3 -B tools/read_status_safe.py --command can
```

6. 如果 ID2 online，再做正负点动：

```sh
python3 -B tools/test_pulse_safe.py --id 2 --mv 6000 --ms 100 --no-reset
python3 -B tools/test_pulse_safe.py --id 2 --mv -6000 --ms 100 --no-reset
```

正常现象：

- `status` 里 ID2 是 `online`
- `can` 里状态是 `running`
- 正负点动都有角度变化，`dq` 一正一负，幅度接近
- 电机只轻微转动，不尖叫、不抖、不乱转
- `tx_fail` 不持续增加

异常处理：

- 没有 USB 串口：换 Type-C 线/方向/接口，必要时重启 Mac。
- ID2 offline：检查 CANH/CANL/GND、YYT 主电源、ID2 固件是否烧在正确板子上。
- 点动 `dq≈0`：断电重新上电，让 sweep-align 重跑，再测一次。
- 抖动、尖叫、过流、乱转：立刻断动力电源，保留串口输出再分析。

## Drive 固件目标

推荐使用 `DriveFirmware` 的新目标：

```sh
cd /Users/ylris/轮腿/ParallelLegRobot
make -C DriveFirmware DRIVE_ID=2 sweep-align-id
openocd -f interface/stlink.cfg -f target/stm32g4x.cfg \
  -c "adapter speed 100; init; reset halt; program DriveFirmware/build/turing_CBU6.bin 0x08000000 verify reset; shutdown"
```

同一流程按物理 ST-Link 连接依次替换 `DRIVE_ID=1/2/5/6`。不要在 ST-Link 还接着 ID2 时烧 ID1/5/6。

当前 sweep-align 默认参数：

- `MOTOR_ALIGN_ONLY=1`
- `MOTOR_POLE_PAIRS=14.0f`
- `MOTOR_ALIGN_VOLTAGE=12.0f`
- `MOTOR_ALIGN_AVG_SAMPLES=32`
- `MOTOR_ALIGN_AVG_DELAY_MS=2U`
- `FOC_MODULATION_LIMIT=1.0f`
- `CAN_MAX_COMMAND_VOLTAGE=12.0f`
- `CAN_FEEDBACK_PERIOD_US=5000U`
- `DRIVE_AUTO_ZERO_HOLD=0`
- `YYT_DISABLE_OUTPUT=0`

## ESP32 主控状态

- 默认环境：`esp32-c3-devkitm-1`
- 当前编译通过。
- 已改为上电 `disarmed`。
- 已关闭上电自动 fixed-pose hold。
- 已关闭 `YYT_ALLOW_UNTESTED_DIRS` 绕过，必须点动 ID1/2/5/6 后才允许 `confirm_dirs`。
- 串口命令以 `status`、`can`、`dirs`、`arm`、`test`、`stop`、`disarm` 为主。
- 当前阶段不要使用 `height`、`stand`、`balance on`。

## 四块腿电机通过标准

- ID1/ID2/ID5/ID6 都能稳定 online。
- 每个 ID 的 `test <id> 6000 100` 和 `test <id> -6000 100` 都能产生可预测方向。
- 点动后角度反馈变化合理，正负 `dq` 幅度接近。
- 无明显抖动、尖叫、过流、乱跳。
- CAN 不掉线，`tx_fail` 不持续增加。

四块都通过以后，再装回机械腿，重新做机械零点、方向确认、腿高保持。

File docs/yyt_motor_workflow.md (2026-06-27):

# YYT MiniOdrive motor workflow

This repository is the source of truth for the robot firmware and motor driver firmware.

For the latest continuation state, read `docs/current_handoff.md` first. That
file records the current flashed diagnostic firmware, last safe state, and the
next ST-Link/CAN command-path check.

## Motor ID map

Physical positions are recorded in the side-view drawing coordinates used during bring-up:

| Side-view position | Drive ID | Role |
| --- | ---: | --- |
| upper-left | 1 | leg joint motor |
| lower-left | 2 | leg joint motor |
| upper-right | 5 | leg joint motor |
| lower-right | 6 | leg joint motor |
| left-leg wheel | 3 | wheel motor |
| right-leg wheel | 4 | wheel motor |

## Current recommended leg-drive route

For the current bring-up, tune the YYT MiniOdrive boards as bottom-level
voltage actuators first:

- build each board with `MOTOR_ALIGN_ONLY=1`
- let the drive run sweep-align at power-up
- average multiple encoder samples after the rotor settles before saving the
  electrical zero
- keep `DRIVE_AUTO_ZERO_HOLD=0`
- command the motor only through CAN mV voltage commands
- let the ESP32-C3 main controller handle joint direction checks, leg height,
  and later whole-body control

Build one drive while ST-Link is physically connected to that exact YYT board:

```sh
cd /Users/ylris/轮腿/ParallelLegRobot
make -C DriveFirmware DRIVE_ID=2 sweep-align-id
openocd -f interface/stlink.cfg -f target/stm32g4x.cfg \
  -c "adapter speed 100; init; reset halt; program DriveFirmware/build/turing_CBU6.bin 0x08000000 verify reset; shutdown"
```

Replace `DRIVE_ID=2` with `1`, `5`, or `6` only after moving ST-Link to that
physical board.

After flashing, verify through the ESP32 serial console:

```text
status
can
arm
test 2 6000 100
test 2 -6000 100
stop
disarm
```

Expected result: the tested ID is online, positive and negative pulses produce
opposite `dq` signs with similar magnitude, and CAN `tx_fail` does not keep
increasing.

Current sweep-align zero sampling defaults:

| Parameter | Value | Meaning |
| --- | ---: | --- |
| `MOTOR_ALIGN_AVG_SAMPLES` | `32` | number of encoder samples after settle |
| `MOTOR_ALIGN_AVG_DELAY_MS` | `2U` | delay between samples |
| `CAN_FEEDBACK_PERIOD_US` | `5000U` | feedback period for sweep-align actuator builds |

The firmware uses a circular average of the sampled electrical angle, so values
near 0 and 2π are averaged correctly.

The table below records older packaged ID builds. Treat it as history unless a
handoff note explicitly says those files were just flashed.

## Packaged legacy leg-drive IDs

| Joint | Drive ID | Firmware |
| --- | ---: | --- |
| Side-view upper-left | 1 | `DriveFirmware/firmware_ids/turing_CBU6_id1_6v.elf` |
| Side-view lower-left | 2 | `DriveFirmware/firmware_ids/turing_CBU6_id2_6v.elf` |
| Side-view upper-right | 5 | `DriveFirmware/firmware_ids/turing_CBU6_id5_6v.elf` |
| Side-view lower-right | 6 | `DriveFirmware/firmware_ids/turing_CBU6_id6_6v.elf` |

## Verified drive direction

| Drive ID | Joint | Verified command direction | Main-controller `drive_sign` |
| ---: | --- | --- | ---: |
| 6 | Side-view lower-right | negative command, tested after reflashing board as ID6 | -1 |

## Build all ID firmwares

```sh
cd DriveFirmware
make ids
```

## Flash one drive

```sh
tools/flash_yyt_id.sh 1
tools/flash_yyt_id.sh 2
tools/flash_yyt_id.sh 5
tools/flash_yyt_id.sh 6
```

## Mechanical zero

The FOC electrical zero belongs to the motor driver. The robot leg mechanical zero belongs to the main controller.

Do not guess mechanical zero offsets. Put the robot in the standby pose, read each motor angle, then write those measured offsets into `config/leg_calibration.json`.

For the current ID6 bring-up, the YYT drive firmware also recognizes a temporary command sentinel:

```text
zero6
```

The ESP32-C3 main controller sends `2345 mV` in the ID6 command slot. The ID6 YYT firmware treats that sentinel as a local zero-position hold request, moves toward `DRIVE_ZERO_RAD=1.991`, then holds with its local PI position loop. Use `stop`, `holdoff`, or `disarm` to exit.

Current ID6 field-tested zero-hold build, confirmed usable on 2026-06-19:

```sh
make -C DriveFirmware id6-zero-hold-current
make -C DriveFirmware flash-id6-zero-hold-current
```

That target builds ID6 with `KP=12.0`, `KI=3.2`, `KD=0.0`, `DRIVE_AUTO_ZERO_DEADBAND_RAD=0.02f`, `DRIVE_AUTO_ZERO_HOLD_LIMIT=12.0f`, `DRIVE_AUTO_ZERO_APPROACH_VOLTAGE=12.0f`, and `FOC_MODULATION_LIMIT=1.0f`. The motor still has audible whine at hold, but this version was acceptable in field testing because it did not show the severe shaking seen with the later `KP=8.0` and `DRIVE_AUTO_ZERO_DEADBAND_RAD=0.08f` test build.

Current ID1 FOC voltage-mode experiment, tested on 2026-06-19:

```sh
make -C DriveFirmware DRIVE_ID=1 \
  MOTOR_AUTO_ELECTRIC_ZERO=0 \
  MOTOR_ZERO_ELECTRIC_ANGLE=0.576f \
  MOTOR_SENSOR_DIRECTION=1.0f \
  MOTOR_POLE_PAIRS=11.0f \
  MOTOR_SKIP_BOOT_SWEEP=1 \
  FOC_MODULATION_LIMIT=1.0f \
  CAN_MAX_COMMAND_VOLTAGE=12.0f \
  CAN_SPIN_TEST_VOLTAGE=12.0f \
  CAN_SPIN_TEST_VELOCITY=0.05f \
  all
```

This build includes the FOC negative-`Uq` phase-flip fix in `DriveFirmware/FOC/FOC.c`. It does not auto-hold or sweep on boot. The matching backup is:

```text
backups/yyt_firmware_20260619_035115/id1_foc_zero_0p576_neg_uq_fix_no_phase_scan/
```

Important status: this ID1 FOC zero is not yet validated as stable. An initial test appeared to move, but the result did not reproduce after reflashing the same backup. Treat the `0.576f` zero as an experiment, not a confirmed calibration.

Latest reproducible ID1 status:

| Command | Duration | Result |
| --- | ---: | --- |
| `test 1 12000 300` | 300 ms | `dq=0.000 rad` after retest |
| `v 1 4321` | 1000 ms | `dq=0.000 rad` after retest |
| `v 1 -4321` | 1000 ms | about `dq=-0.010 rad` after retest |

The earlier absolute phase scan result (`7004/7005`) is not currently considered reliable because later A/B testing showed it likely included mechanical settling or rebound. Keep `CAN_PHASE_SCAN_ENABLE=0` for normal builds so `7000..7005 mV` remain ordinary voltage commands.

Current ID5 direct UART debug build, flashed and verified on 2026-06-19:

```sh
make -C DriveFirmware id5-uart-debug
make -C DriveFirmware flash-id5-uart-debug
```

This target builds ID5 with `DRIVE_AUTO_ZERO_HOLD=0`, `YYT_UART_DEBUG=1`, and `FOC_MODULATION_LIMIT=1.0f`. It does not use the ESP32-C3 main controller or CAN for tuning. Connect a USB-TTL adapter directly to the YYT drive UART:

| USB-TTL | YYT drive |
| --- | --- |
| RX | PB6 / USART1_TX |
| TX | PB7 / USART1_RX |
| GND | GND |

The UART is `115200 8N1`. The debug firmware boots `disarmed`, sends `0 mV`, and requires the `arm` command before any motion. Start with low-voltage pulses:

```text
status
arm
pulse 300 50
pulse -300 50
stop
disarm
```

For local ID5 hold tuning, use small limits first:

```text
pid 1000 0 50 800 -1
hold current
```

Units are integer-only in the serial protocol: `pulse/v/limit` use mV, `target/hold` use raw single-turn mrad, and `pid` gains use mV/rad. The default hold parameters are `sign=-1`, `Kp=1000 mV/rad`, `Ki=0`, `Kd=50 mV/(rad/s)`, and `limit=800 mV`. Avoid the earlier ID5 drive-side auto-zero builds during debugging; the ID5 versions tested with high-voltage auto-hold shook severely.

ID5 copy of the ID6 field-tested zero-hold parameters, flashed and verified on 2026-06-19:

```sh
make -C DriveFirmware DRIVE_ID=5 DRIVE_AUTO_ZERO_HOLD=1 \
  DRIVE_AUTO_ZERO_OUTPUT_SIGN=1 \
  DRIVE_AUTO_ZERO_HOLD_KP=12.0f \
  DRIVE_AUTO_ZERO_HOLD_KI=3.2f \
  DRIVE_AUTO_ZERO_HOLD_KD=0.0f \
  DRIVE_AUTO_ZERO_HOLD_LIMIT=12.0f \
  DRIVE_AUTO_ZERO_APPROACH_VOLTAGE=12.0f \
  DRIVE_AUTO_ZERO_DEADBAND_RAD=0.02f \
  FOC_MODULATION_LIMIT=1.0f \
  YYT_UART_DEBUG=0 all
```

This keeps the board identity as `DRIVE_ID=5` and uses ID5's compiled zero offset `DRIVE_ZERO_RAD=0.161f`; only the ID6 zero-hold behavior and gains are copied. It boots directly into drive-side zero hold with no start delay and no hold timeout.

Recommended standby pose:

- Left and right legs are symmetric.
- Wheels/feet are under the body.
- The leg length is medium, not fully folded and not fully extended.
- All links are away from hard mechanical stops.

## ESP32C3 main-board CAN wiring

The custom ESP32C3 main board uses these internal CAN pins:

| Signal | ESP32C3 GPIO | Note |
| --- | ---: | --- |
| CAN_TX | IO6 | Internal signal from ESP32C3 to TJA1050T TXD |
| CAN_RX | IO7 | Internal signal from TJA1050T RXD to ESP32C3 |

Do not wire IO6 or IO7 directly to a YYT MiniOdrive board. IO6/IO7 are logic-level signals inside the main board. The external robot CAN bus is after the TJA1050T transceiver:

| Main board external bus | Connects to YYT MiniOdrive |
| --- | --- |
| CAN+ | CANH |
| CAN- | CANL |
| GND | GND or power negative |

USB must stay connected between the computer and the main board while calibrating. It powers and programs the ESP32C3 and provides the serial console. The YYT MiniOdrive boards still need their own motor supply. For first CAN bring-up, use one YYT board at a time with 12 V and a low current limit.

The ESP32 control-board Gerber flying-probe data shows these repeated external connector pinouts:

| Main-board connector | Pin 1 | Pin 2 | Pin 3 | Pin 4 | Pin 5 | Pin 6 |
| --- | --- | --- | --- | --- | --- | --- |
| U5 | CAN- | CAN+ | GND | VIN | GND | GND |
| U7 | CAN- | CAN+ | GND | VIN | GND | GND |
| U10 | CAN- | CAN+ | GND | VIN | GND | GND |
| U12 | CAN- | CAN+ | GND | VIN | GND | GND |
| U13 | CAN- | CAN+ | GND | VIN | GND | GND |
| U14 | CAN- | CAN+ | GND | VIN | GND | GND |

The YYT MiniOdrive V2.7 `.epro` PCB data shows the CAN connector as `CN2`:

| YYT MiniOdrive connector | Pin 1 | Pin 2 | Pin 3 | Pin 4 |
| --- | --- | --- | --- | --- |
| CN2 | CANL | CANH | not connected in PCB data | not connected in PCB data |

Therefore, for the CAN pair itself:

| Main board | YYT MiniOdrive |
| --- | --- |
| connector pin 1, CAN- | CN2 pin 1, CANL |
| connector pin 2, CAN+ | CN2 pin 2, CANH |

Do not use the main-board connector VIN pin to power the YYT MiniOdrive unless the power path has been intentionally designed and checked. During bring-up, power the YYT board from the bench supply and use the connector only for CAN-/CAN+/GND.

## CAN zero calibrator

Build and flash the safe zero-voltage CAN calibrator:

```sh
cd /Users/ylris/轮腿/ParallelLegRobot
pio run -e yyt-can-zero -t upload --upload-port /dev/cu.usbmodem1301
```

Open or query the serial console at 115200 baud:

```sh
pio device monitor --port /dev/cu.usbmodem1301 --baud 115200
```

Quick one-shot status query:

```sh
cd /Users/ylris/轮腿/ParallelLegRobot
tools/can_status.py
```

Manual serial commands:

| Command | Meaning |
| --- | --- |
| `status` | Print TWAI/CAN diagnostics and current ID1/2/5/6 angles |
| `z` | Capture current angles as mechanical-zero candidates |
| `help` | Print command list |

Normal first success with only ID1 connected:

```text
online: ID1=yes ID2=no ID5=no ID6=no
```

Normal success with all four leg drives connected:

```text
online: ID1=yes ID2=yes ID5=yes ID6=yes
```

## Current CAN fault signature

If the serial output looks like this:

```text
CAN RX GPIO7, CAN TX GPIO6, 1 Mbps
CAN state=running tx_fail=0 recoveries=10 tx_pause=yes bus_error=33505 tx_err=128 rx_err=0 tx_queue=1 rx_queue=0 ...
online: ID1=no ID2=no ID5=no ID6=no
```

the ESP32C3 firmware is running with the correct pins and is protecting itself by clearing the transmit queue, but no powered CAN node is acknowledging frames. Check hardware before changing protocol code:

1. Connect only one YYT MiniOdrive first, preferably the ID1 board.
2. Keep main-board USB connected to the computer.
3. Power the YYT board from the bench supply, starting around 12 V with a low current limit.
4. Confirm common ground: main-board GND to YYT GND or supply negative.
5. Connect main-board connector pin 1 `CAN-` to YYT `CN2 pin 1 CANL`.
6. Connect main-board connector pin 2 `CAN+` to YYT `CN2 pin 2 CANH`.
7. If still offline, swap only CANH and CANL once and query `status` again.
8. If still offline, reflash that YYT board with its intended ID firmware and try again.

After changing wiring or power, query with a delayed CAN status so the controller has time to attempt real bus traffic:

```sh
python3 -B tools/read_status_safe.py --command can --pre-command-delay 6 --read 3
```

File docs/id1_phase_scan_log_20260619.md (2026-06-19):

# ID1 Phase Scan Log - 2026-06-19

This log captures the current ID1 bring-up state so a new conversation can
continue without relying on chat history.

## Safety / Connection

- User confirmed ST-Link is physically connected to the ID1 YYT drive board.
- Main controller serial port: `/dev/cu.usbmodem11301`.
- ST-Link target: STM32G431, target voltage about `3.22 V`.
- Last verified safe state after motion tests: main controller `armed=no`,
  `hold=off`, `ID1/ID2/ID5/ID6 online`.
- Important ESP32-C3 serial handling: keep `DTR=True`, `RTS=False`. On this
  board, `DTR=False` can hold BOOT low and enter ROM download mode.

## Firmware Currently On ID1

ID1 currently has the phase-scan diagnostic firmware:

```text
backups/yyt_firmware_20260619_035115/id1_phase_scan_12v_diag/turing_CBU6.bin
```

SHA256:

```text
f3814133f5d251e32cc70391682bf37cb5398917ec9bdf414f745be0fdbbf73d
```

Build settings:

```text
DRIVE_ID=1
MOTOR_SKIP_BOOT_SWEEP=1
MOTOR_ZERO_ELECTRIC_ANGLE=0.576f
MOTOR_POLE_PAIRS=11.0f
FOC_MODULATION_LIMIT=1.0f
CAN_PHASE_SCAN_ENABLE=1
CAN_PHASE_SCAN_VOLTAGE=12.0f
CAN_MAX_COMMAND_VOLTAGE=12.0f
DRIVE_AUTO_ZERO_HOLD=0
YYT_DISABLE_OUTPUT=0
```

Behavior:

- No power-on zero hold.
- No boot motor sweep.
- Normal voltage command still works.
- `test 1 7000..7005 <ms>` maps to six fixed electrical phase tests.
- `test 1 -7000..-7005 <ms>` maps to the same six phases with negative Uq.

## Command Path Evidence

No-output RX-debug diagnostic firmware previously proved the CAN command reaches
ID1 internally:

- During `v 1 12000`, ID1 RAM showed `can_voltage_cmd=12.0`, `mode=7`,
  `uq_limit=0.0`, and centered PWM because output was intentionally disabled.
- The automatic RX debug verdict printed FAIL only because later feedback frame
  `0x106` overwrote `can_last_rx_*`; do not treat that as command-path failure.

The restored output-enabled firmware was then tested during `v 1 12000` and
ST-Link RAM showed:

```text
uq_limit=12.0
mode=7.0
can_enabled=1
can_voltage_cmd=12.0
u_a=0.0
u_b=8400.0
u_c=8400.0
vbus=4.7856
zero_electric_angle=0.576
```

This means ID1 received the 12 V command and the firmware drove PWM at full
modulation. The problem is not "main voltage command too small"; it is in the
FOC electrical angle / phase / pole-pair / wiring interpretation.

## Phase Scan Results

After flashing `id1_phase_scan_12v_diag`, short phase pulses gave:

```text
test 1 7000 120  -> dq about -0.004 rad
test 1 7001 120  -> dq about  0.000 rad
test 1 7002 120  -> dq about -0.006 rad
test 1 7003 120  -> dq about -0.001 rad
test 1 7004 120  -> dq about  0.000 rad
test 1 7005 120  -> dq about +0.269 rad
```

`7005` is the first clearly effective fixed electrical phase observed on ID1.
This proves the motor/driver can produce meaningful torque at 12 V, and the
normal FOC angle used by the previous firmware is not aligned.

The attempted full positive/negative scan was interrupted when USB serial
entered ESP32-C3 ROM download mode. Scripts were then patched to keep BOOT
released by using `DTR=True`, `RTS=False`.

## Normal FOC Candidate Result

After the `7005` result, an ordinary output-enabled CAN voltage-mode firmware
was built and flashed to ID1:

```text
backups/yyt_firmware_20260619_035115/id1_foc_zero_3p294_pp11_candidate/turing_CBU6.bin
```

SHA256:

```text
39d13baf03002ebbabe9a7441aa3be702cb291da50b9f856500139daf9e91545
```

Build settings:

```text
DRIVE_ID=1
MOTOR_SKIP_BOOT_SWEEP=1
MOTOR_ZERO_ELECTRIC_ANGLE=3.294f
MOTOR_POLE_PAIRS=11.0f
FOC_MODULATION_LIMIT=1.0f
CAN_MAX_COMMAND_VOLTAGE=12.0f
DRIVE_AUTO_ZERO_HOLD=0
YYT_DISABLE_OUTPUT=0
CAN_PHASE_SCAN_ENABLE=0
```

Short-pulse result:

```text
test 1 6000 80
q_before=-1.1822
q_after=-1.4502
dq=-0.2680 rad

test 1 -6000 80
q_before=-1.0962
q_after=-1.0592
dq=+0.0370 rad
```

This is a major improvement over the previous `0.576f` zero firmware, where
even `12000 mV` barely moved ID1. The current candidate proves normal FOC
voltage mode can produce clear motion on ID1. However, the two directions are
not symmetric yet, so this should be treated as a working base, not final
calibration.

After this test, `disarm` was sent and the controller reported `armed=no`.

## Candidate Next Step

Do not tune PID yet. First verify normal CAN voltage mode is coherent in both
directions and decide the sign convention.

Immediate next test after this candidate:

```sh
Build and test the second candidate:
MOTOR_POLE_PAIRS=14
MOTOR_ZERO_ELECTRIC_ANGLE=2.193f
```

If pp14 is not better, return to the pp11/3.294 candidate and tune around it.

## PP14 Candidate Result

The second ordinary FOC candidate was built and flashed:

```text
backups/yyt_firmware_20260619_035115/id1_foc_zero_2p193_pp14_candidate/turing_CBU6.bin
```

SHA256:

```text
73e49b70a195ef12a96800b7190d4154bfd4acd77ec1c2be7b1b3a9d3f6d1d38
```

Build settings:

```text
DRIVE_ID=1
MOTOR_SKIP_BOOT_SWEEP=1
MOTOR_ZERO_ELECTRIC_ANGLE=2.193f
MOTOR_POLE_PAIRS=14.0f
FOC_MODULATION_LIMIT=1.0f
CAN_MAX_COMMAND_VOLTAGE=12.0f
DRIVE_AUTO_ZERO_HOLD=0
YYT_DISABLE_OUTPUT=0
CAN_PHASE_SCAN_ENABLE=0
```

Short-pulse result:

```text
test 1 6000 80
q_before=-1.0592
q_after=-1.6012
dq=-0.5420 rad

test 1 -6000 80
q_before=-1.3022
q_after=-1.2772
dq=+0.0250 rad
```

pp14/2.193 has a stronger positive response than pp11/3.294, but reverse
response is still weak. Current ID1 firmware is this pp14 candidate. After the
tests, `disarm` was sent and status confirmed `armed=no`, `ID1/ID2/ID5/ID6
online`.

Next technical target: fix the direction asymmetry before PID or position hold.
Likely areas are electrical zero offset around pp14/2.193, phase order, or the
negative-Uq/angle-shift handling in `FOC.c`.

For reference, the derivation used for the first candidate was:

At the local position before the strong `7005` pulse, the main controller showed:

```text
raw about -0.367 rad
q about -1.056 rad
```

The strongest fixed phase was `7005`, which corresponds to phase index 5:

```text
phase_input = 5*pi/3 = 5.23599 rad
```

Candidate electrical zero values derived from that observation:

```text
MOTOR_POLE_PAIRS=11, zero_for_input_phase ~= 3.294 rad  <-- tested; works
MOTOR_POLE_PAIRS=14, zero_for_input_phase ~= 2.193 rad
```
Keep `DRIVE_AUTO_ZERO_HOLD=0` until normal FOC voltage motion and direction are
verified.

## Useful Commands

Safe state:

```sh
python3 -B tools/read_status_safe.py --port /dev/cu.usbmodem11301 --command disarm --pre-command-delay 0.5 --read 1.0
```

Reflash the current ID1 phase-scan diagnostic, if needed:

```sh
cd /Users/ylris/轮腿/ParallelLegRobot/DriveFirmware
openocd -f interface/stlink.cfg -f target/stm32g4x.cfg -c "adapter speed 100; program ../backups/yyt_firmware_20260619_035115/id1_phase_scan_12v_diag/turing_CBU6.bin 0x08000000 verify reset exit"
```

Run one phase pulse:

```sh
python3 tools/test_pulse_safe.py --port /dev/cu.usbmodem11301 --id 1 --mv 7005 --ms 120
```

Test the current normal FOC candidate:

```sh
python3 tools/test_pulse_safe.py --port /dev/cu.usbmodem11301 --id 1 --mv 6000 --ms 80
python3 tools/test_pulse_safe.py --port /dev/cu.usbmodem11301 --id 1 --mv -6000 --ms 80
```

Run the safe phase scan helper:

```sh
python3 tools/phase_scan_safe.py --port /dev/cu.usbmodem11301 --id 1 --ms 120 --negative
```

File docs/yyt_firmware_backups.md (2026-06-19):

# YYT Firmware Backups

## ID1 - Before Unified Refresh

The ID1 board flash was backed up before refreshing ID1 to the unified main-controller-driven firmware.

Backup file:

```text
backups/yyt_firmware_20260619_035115/id1_before_unified/id1_board_flash_0x08000000_128k.bin
```

Restore command:

```sh
cd /Users/ylris/轮腿/ParallelLegRobot/DriveFirmware
openocd -f interface/stlink.cfg -f target/stm32g4x.cfg -c "adapter speed 100; program ../backups/yyt_firmware_20260619_035115/id1_before_unified/id1_board_flash_0x08000000_128k.bin 0x08000000 verify reset exit"
```

SHA256:

```text
c832d74ba2b95694cfbcc2e81a691490b01550b9779125c34cd6162136773dfb
```

## ID1 - Refreshed Unified Firmware

ID1 was refreshed with the unified main-controller-driven firmware after the raw board flash backup was created.

Build settings:

```text
DRIVE_ID=1
DRIVE_AUTO_ZERO_HOLD=0
YYT_UART_DEBUG=0
MOTOR_SKIP_BOOT_SWEEP=1
FOC_MODULATION_LIMIT=1.0f
```

Behavior:

- Does not automatically hold zero on power-up.
- Skips the power-on motor sweep.
- Waits for main-controller/CAN commands for motion and future leg-height control.

Flashed file copy:

```text
backups/yyt_firmware_20260619_035115/id1_refreshed_unified/turing_CBU6_id1_unified_no_auto_hold_skip_boot_sweep.bin
```

SHA256:

```text
8fbff9493639bcac29cf00affe1c29884fec0938b032780d8f40b262cff33dd8
```

## ID1 - No-Output CAN Slot Diagnostic

This diagnostic firmware was flashed to the current ST-Link target on
2026-06-19 while debugging why the ESP32-C3 main controller printed
`ID1 cmd=+12000 mV` but the drive-side RAM read showed `can_voltage_cmd=0.0`.

Build settings:

```text
DRIVE_ID=1
YYT_DISABLE_OUTPUT=1
MOTOR_AUTO_ELECTRIC_ZERO=0
MOTOR_ZERO_ELECTRIC_ANGLE=0.576f
MOTOR_SENSOR_DIRECTION=1.0f
MOTOR_POLE_PAIRS=11.0f
MOTOR_SKIP_BOOT_SWEEP=1
FOC_MODULATION_LIMIT=1.0f
CAN_MAX_COMMAND_VOLTAGE=12.0f
CAN_SPIN_TEST_VOLTAGE=12.0f
CAN_SPIN_TEST_VELOCITY=0.05f
```

Behavior:

- Keeps the board identity as `DRIVE_ID=1`.
- Receives and responds on CAN.
- Forces `uq_limit=0`, so it is for RAM/CAN diagnosis only and should not
  generate motor torque.

Flashed file copy:

```text
backups/yyt_firmware_20260619_035115/id1_no_output_can_slot_diag/turing_CBU6.bin
```

SHA256:

```text
df793d4d7f9019ad4723fd05b0d483e954d65ee128be19bc2f40ad664a641caa
```

## ID1 - No-Output CAN RX Debug Diagnostic

This is the newer no-output diagnostic build compiled after adding RAM-visible
CAN RX debug variables to `DriveFirmware/Core/Src/can_bridge.c`. It was flashed
to the confirmed ID1 target and used to prove that ID1 receives `v 1 12000`
internally as `can_voltage_cmd=12.0`. Confirm the ST-Link is physically on the
intended ID1 YYT board before flashing again.

Additional debug variables:

```text
can_last_rx_count
can_last_rx_std_id
can_last_rx_data[8]
can_last_rx_slot
can_last_rx_mv
can_last_rx_accepted
```

Flashed-file candidate:

```text
backups/yyt_firmware_20260619_035115/id1_no_output_can_rx_debug_pending/turing_CBU6.bin
```

SHA256:

```text
88723139101832c040a6c965f5edeed2db41a158de867a7c4e8d501d9d3bb53d
```

Use `tools/decode_yyt_ram_dump.py` with the matching ELF to decode the SRAM
dump after a `v 1 12000` command window.

Preferred wrapper after confirming the ST-Link is physically on ID1:

```sh
python3 tools/run_id1_can_rx_diag.py --port /dev/cu.usbmodem11301 --flash --confirm-stlink-id1
```

## ID1 - Phase Scan 12 V Diagnostic

This is the current ID1 firmware as of 2026-06-19 06:24 CST. It was used after
drive RAM proved that normal `v 1 12000` reaches full PWM but produces little
useful motion. The purpose is to test fixed electrical phases through CAN
commands `7000..7005`.

Build settings:

```text
DRIVE_ID=1
MOTOR_SKIP_BOOT_SWEEP=1
MOTOR_ZERO_ELECTRIC_ANGLE=0.576f
MOTOR_POLE_PAIRS=11.0f
FOC_MODULATION_LIMIT=1.0f
CAN_PHASE_SCAN_ENABLE=1
CAN_PHASE_SCAN_VOLTAGE=12.0f
CAN_MAX_COMMAND_VOLTAGE=12.0f
DRIVE_AUTO_ZERO_HOLD=0
YYT_DISABLE_OUTPUT=0
```

Behavior:

- Does not automatically hold zero on power-up.
- Skips the power-on motor sweep.
- Responds to normal CAN voltage commands.
- Treats `7000..7005` as fixed electrical phase tests.

Flashed file copy:

```text
backups/yyt_firmware_20260619_035115/id1_phase_scan_12v_diag/turing_CBU6.bin
```

SHA256:

```text
f3814133f5d251e32cc70391682bf37cb5398917ec9bdf414f745be0fdbbf73d
```

Restore command:

```sh
cd /Users/ylris/轮腿/ParallelLegRobot/DriveFirmware
openocd -f interface/stlink.cfg -f target/stm32g4x.cfg -c "adapter speed 100; program ../backups/yyt_firmware_20260619_035115/id1_phase_scan_12v_diag/turing_CBU6.bin 0x08000000 verify reset exit"
```

## ID1 - FOC Zero 3.294, Pole Pairs 11 Candidate

This is the current ordinary output-enabled FOC candidate as of 2026-06-19
06:28 CST. It was derived from the phase-scan result where `test 1 7005 120`
produced clear motion.

Build settings:

```text
DRIVE_ID=1
MOTOR_SKIP_BOOT_SWEEP=1
MOTOR_ZERO_ELECTRIC_ANGLE=3.294f
MOTOR_POLE_PAIRS=11.0f
FOC_MODULATION_LIMIT=1.0f
CAN_MAX_COMMAND_VOLTAGE=12.0f
DRIVE_AUTO_ZERO_HOLD=0
YYT_DISABLE_OUTPUT=0
CAN_PHASE_SCAN_ENABLE=0
```

Verification:

```text
test 1 6000 80 -> dq=-0.2680 rad
test 1 -6000 80 -> dq=+0.0370 rad
```

The candidate is usable enough to prove normal FOC voltage motion, but the
response is asymmetric and not final.

Flashed file copy:

```text
backups/yyt_firmware_20260619_035115/id1_foc_zero_3p294_pp11_candidate/turing_CBU6.bin
```

SHA256:

```text
39d13baf03002ebbabe9a7441aa3be702cb291da50b9f856500139daf9e91545
```

Restore command:

```sh
cd /Users/ylris/轮腿/ParallelLegRobot/DriveFirmware
openocd -f interface/stlink.cfg -f target/stm32g4x.cfg -c "adapter speed 100; program ../backups/yyt_firmware_20260619_035115/id1_foc_zero_3p294_pp11_candidate/turing_CBU6.bin 0x08000000 verify reset exit"
```

## ID1 - FOC Zero 2.193, Pole Pairs 14 Candidate

This is the current ordinary output-enabled FOC candidate as of 2026-06-19
06:31 CST. It was tested because the original YYT MiniOdrive source uses
`pole_pairs=14`.

Build settings:

```text
DRIVE_ID=1
MOTOR_SKIP_BOOT_SWEEP=1
MOTOR_ZERO_ELECTRIC_ANGLE=2.193f
MOTOR_POLE_PAIRS=14.0f
FOC_MODULATION_LIMIT=1.0f
CAN_MAX_COMMAND_VOLTAGE=12.0f
DRIVE_AUTO_ZERO_HOLD=0
YYT_DISABLE_OUTPUT=0
CAN_PHASE_SCAN_ENABLE=0
```

Verification:

```text
test 1 6000 80 -> dq=-0.5420 rad
test 1 -6000 80 -> dq=+0.0250 rad
```

It has the strongest positive response so far, but reverse response is still
weak. Do not treat it as final position-hold firmware.

Flashed file copy:

```text
backups/yyt_firmware_20260619_035115/id1_foc_zero_2p193_pp14_candidate/turing_CBU6.bin
```

SHA256:

```text
73e49b70a195ef12a96800b7190d4154bfd4acd77ec1c2be7b1b3a9d3f6d1d38
```

Restore command:

```sh
cd /Users/ylris/轮腿/ParallelLegRobot/DriveFirmware
openocd -f interface/stlink.cfg -f target/stm32g4x.cfg -c "adapter speed 100; program ../backups/yyt_firmware_20260619_035115/id1_foc_zero_2p193_pp14_candidate/turing_CBU6.bin 0x08000000 verify reset exit"
```

## ID2 - Before Unified Refresh

The ID2 board flash was backed up before refreshing ID2 to the unified main-controller-driven firmware.

Backup file:

```text
backups/yyt_firmware_20260619_035115/id2_before_unified/id2_board_flash_0x08000000_128k.bin
```

Restore command:

```sh
cd /Users/ylris/轮腿/ParallelLegRobot/DriveFirmware
openocd -f interface/stlink.cfg -f target/stm32g4x.cfg -c "adapter speed 100; program ../backups/yyt_firmware_20260619_035115/id2_before_unified/id2_board_flash_0x08000000_128k.bin 0x08000000 verify reset exit"
```

SHA256:

```text
e5613cd38b18c3c9b4d15a2a031831377e73995cb9945099c689df9c0e568ffc
```

## ID2 - Refreshed Unified Firmware

ID2 was refreshed with the unified main-controller-driven firmware after the raw board flash backup was created.

Build settings:

```text
DRIVE_ID=2
DRIVE_AUTO_ZERO_HOLD=0
YYT_UART_DEBUG=0
MOTOR_SKIP_BOOT_SWEEP=1
FOC_MODULATION_LIMIT=1.0f
```

Behavior:

- Does not automatically hold zero on power-up.
- Skips the power-on motor sweep.
- Waits for main-controller/CAN commands for motion and future leg-height control.

Flashed file copy:

```text
backups/yyt_firmware_20260619_035115/id2_refreshed_unified/turing_CBU6_id2_unified_no_auto_hold_skip_boot_sweep.bin
```

SHA256:

```text
1491c12358d796054f3a5868a36cf01b32030115d5534cdb2b215e422a229b2c
```

## ID5 - Refreshed Unified Firmware

ID5 was refreshed with the unified main-controller-driven firmware after the earlier UART/debug tuning builds.

Build settings:

```text
DRIVE_ID=5
DRIVE_AUTO_ZERO_HOLD=0
YYT_UART_DEBUG=0
MOTOR_SKIP_BOOT_SWEEP=1
FOC_MODULATION_LIMIT=1.0f
```

Behavior:

- Does not automatically hold zero on power-up.
- Skips the power-on motor sweep.
- Waits for main-controller/CAN commands for motion and future leg-height control.

Flashed file copy:

```text
backups/yyt_firmware_20260619_035115/id5_refreshed_unified/turing_CBU6_id5_unified_no_auto_hold_skip_boot_sweep.bin
```

SHA256:

```text
40846bbf5288b9caa349d156a39952085aaba23f4712e2f85e9078e081c14e25
```

## ID6 - 上电自动保持零位

The ID6 board firmware that worked well for power-on zero hold was backed up before refreshing ID6 to the unified main-controller-driven firmware.

Backup file:

```text
backups/yyt_firmware_20260619_035115/id6_power_on_zero_hold/id6_board_flash_0x08000000_128k.bin
```

Restore command:

```sh
cd /Users/ylris/轮腿/ParallelLegRobot/DriveFirmware
openocd -f interface/stlink.cfg -f target/stm32g4x.cfg -c "adapter speed 100; program ../backups/yyt_firmware_20260619_035115/id6_power_on_zero_hold/id6_board_flash_0x08000000_128k.bin 0x08000000 verify reset exit"
```

SHA256:

```text
d31dff8dd27d67948f4350c3f6bcdfb7f10df4e1824c080148e09b82c171c58b
```

## ID6 - Refreshed Unified Firmware

After backing up the `上电自动保持零位` firmware, ID6 was refreshed with the unified main-controller-driven firmware.

Build settings:

```text
DRIVE_ID=6
DRIVE_AUTO_ZERO_HOLD=0
YYT_UART_DEBUG=0
MOTOR_SKIP_BOOT_SWEEP=1
FOC_MODULATION_LIMIT=1.0f
```

Behavior:

- Does not automatically hold zero on power-up.
- Skips the power-on motor sweep.
- Waits for main-controller/CAN commands for motion and future leg-height control.

Flashed file copy:

```text
backups/yyt_firmware_20260619_035115/id6_refreshed_unified/turing_CBU6_id6_unified_no_auto_hold_skip_boot_sweep.bin
```

SHA256:

```text
ae634d15087050e1eb68057053662662e5fa62170599aab71669c9cc67a12f4d
```

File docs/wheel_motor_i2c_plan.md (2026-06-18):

# Wheel Motor I2C Plan

This document records the current wheel-motor integration plan.

## Hardware Topology

The ESP32-C3 custom main board is the top-level controller. It uses one shared I2C bus through the power distribution board:

| Signal | ESP32-C3 pin |
| --- | --- |
| I2C SCL | GPIO3 |
| I2C SDA | GPIO4 |

All I2C devices share SDA/SCL/GND. They must have different 7-bit addresses.

| Device | Role | Default address |
| --- | --- | --- |
| MPU6050 | Body IMU | `0x68` |
| STM32F103C8T6 minimum board | Wheel PWM coprocessor | `0x12` |
| Wheel magnetic encoder | Wheel angle feedback | `0x36` |

The current firmware keeps all wheel outputs disabled at boot. Type `wheelarm` before sending PWM.

Physical wheel motor numbering:

| Wheel | Motor ID |
| --- | ---: |
| Left-leg wheel motor | 3 |
| Right-leg wheel motor | 4 |

In the current I2C/PWM bring-up path, commands are still sent as `left` and `right` PWM values; these correspond to motor ID3 and ID4 respectively.

## STM32F103 Wiring

The F103 minimum board firmware in `src/f103_wheel_pwm.cpp` uses these pins:

| Signal | STM32F103 pin | Connect to |
| --- | --- | --- |
| I2C1 SCL | `PB6` | ESP32-C3 `GPIO3` / shared I2C SCL |
| I2C1 SDA | `PB7` | ESP32-C3 `GPIO4` / shared I2C SDA |
| GND | `GND` | ESP32-C3 GND, encoder GND, SimpleFOC GND |
| 3.3 V | `3V3` | 3.3 V logic supply |
| Left wheel PWM | `PA0` | Left SimpleFOC PWM/speed input |
| Right wheel PWM | `PA1` | Right SimpleFOC PWM/speed input |
| Left wheel DIR | `PA2` | Left SimpleFOC direction input, if used |
| Right wheel DIR | `PA3` | Right SimpleFOC direction input, if used |
| Status LED | `PC13` | On-board LED on many BluePill boards |

ST-Link programming wires:

| ST-Link | STM32F103 minimum board |
| --- | --- |
| `GND` | `GND` |
| `3.3V` / `VTref` | `3V3` |
| `SWDIO` / `DIO` | `PA13` / `SWDIO` |
| `SWCLK` / `CLK` | `PA14` / `SWCLK` |

Do not connect 5 V to ESP32-C3 GPIO, F103 GPIO, or I2C pull-ups. The shared I2C bus should be pulled up to 3.3 V.

## STM32F103 PWM Coprocessor Protocol

ESP32-C3 is I2C master. STM32F103 is I2C slave at address `0x12`.

Command `0x10` sets signed wheel PWM:

| Byte | Meaning |
| --- | --- |
| 0 | command register `0x10` |
| 1 | left PWM low byte |
| 2 | left PWM high byte |
| 3 | right PWM low byte |
| 4 | right PWM high byte |

PWM values are signed little-endian `int16_t`, clamped by ESP32 to `-1000..1000`.

Example payload for left `+200`, right `-200`:

```text
0x10 0xC8 0x00 0x38 0xFF
```

The STM32F103 firmware should treat missing I2C writes as a fault and stop PWM after a short timeout, for example 100 ms.

## Wheel Encoder Protocol

The current ESP32 firmware assumes an AS5600-compatible magnetic encoder:

| Address | Register | Meaning |
| --- | --- | --- |
| `0x36` | `0x0C`, `0x0D` | 12-bit raw angle |

The ESP32 converts the raw value to radians:

```text
angle_rad = raw * 2*pi / 4096
```

If the real encoder is not AS5600-compatible, only `readWheelEncoder()` in `src/main.cpp` needs to change.

## ESP32 Serial Commands

| Command | Meaning |
| --- | --- |
| `i2cscan` | Scan shared I2C bus and print detected addresses |
| `wheel` | Print wheel F103/encoder status |
| `wheelarm` | Allow wheel PWM commands, current PWM remains zero |
| `wheeldisarm` | Force wheel PWM to zero and disable wheel commands |
| `wheelpwm <left> <right>` | Send signed PWM to STM32F103, range `-1000..1000` |
| `wheelstream on` | Stream `wheel:angle,pwm_l,pwm_r,status...` lines |
| `wheelstream off` | Stop wheel stream |

Global `stop` and `disarm` also force wheel PWM to zero.

## Bring-up Order

1. Power ESP32-C3 logic only.
2. Run `i2cscan`; expect at least the F103 address and encoder address if connected.
3. Run `wheel`; confirm `f103=online` and `encoder=online`.
4. Power the SimpleFOC wheel power stage with current limit.
5. Run `wheelarm`.
6. Start with very small PWM, for example `wheelpwm 50 50`.
7. Use `wheelstream on` to check encoder angle changes.
8. Run `wheelpwm 0 0`, then `wheeldisarm` after the test.

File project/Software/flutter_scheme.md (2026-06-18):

# VaporOS // Flutter 跨平台轮腿控制器技术方案 (Flutter Technical Spec)

本方案旨在利用 **Flutter** 框架构建一个能够在 Linux (Fedora/GNOME)、Windows、macOS 以及 Android 平板/手机上原生运行的 **Vaporwave 蒸汽波 + ASCII Art** 风格开发者控制台 App，并实现与主控板的 USB 串口通信及低延迟音效合成。

---

## 1. 技术栈选型 (Technology Stack)

*   **UI 渲染引擎**：Flutter SDK (Dart 3.x)
*   **物理串口通信**：
    *   桌面端 (Linux, Windows, macOS): [flutter_libserialport](https://pub.dev/packages/flutter_libserialport) (基于 `libserialport` C 库，对 Fedora 完美支持)
    *   移动端 (Android): [usb_serial](https://pub.dev/packages/usb_serial) (基于 Android USB Host API，免 Root 支持 Android USB OTG 串口通信)
*   **字体库**：[google_fonts](https://pub.dev/packages/google_fonts) (支持 `JetBrains Mono` 和 `IBM Plex Mono`)
*   **低延迟音效引擎**：[soundpool](https://pub.dev/packages/soundpool) (用于机械键盘咔哒声、蜂鸣声等毫秒级响应音效)
*   **状态管理**：`Provider` 或 `flutter_bloc` (处理串口数据流、遥测数据动态刷新)

---

## 2. 依赖配置 (`pubspec.yaml`)

```yaml
name: vapor_coprocessor_controller
description: "Vaporwave CRT Serial Controller for Parallel Leg-Wheel Robot"
publish_to: 'none'
version: 1.0.0+1

environment:
  sdk: '>=3.0.0 <4.0.0'

dependencies:
  flutter:
    sdk: flutter
  
  # 跨平台串口驱动
  flutter_libserialport: ^0.4.0
  usb_serial: ^3.1.0 # (可选：仅限 Android 端使用)
  
  # 状态与工具
  provider: ^6.1.1
  google_fonts: ^6.1.0
  
  # 音效
  soundpool: ^2.3.0
  
  # 动画与矢量处理
  vector_math: ^2.1.4

flutter:
  uses-material-design: true
  assets:
    - assets/sounds/click.wav
    - assets/sounds/boot.wav
    - assets/sounds/hum.wav
```

---

## 3. 核心串口服务实现 (`lib/services/serial_service.dart`)

我们通过统一的抽象接口，使得 UI 层无需关心底层是 Desktop 串口还是 Android OTG 串口。

```dart
import 'dart:async';
import 'dart:convert';
import 'dart:typed_data';
import 'package:flutter/foundation.dart';
import 'package:flutter_libserialport/flutter_libserialport.dart';

class SerialService extends ChangeNotifier {
  SerialPort? _port;
  SerialPortReader? _reader;
  bool _isConnected = false;
  final List<String> _logs = [];
  
  // 遥测数据流控制
  final StreamController<String> _lineStreamController = StreamController<String>.broadcast();
  Stream<String> get lineStream => _lineStreamController.stream;

  bool get isConnected => _isConnected;
  List<String> get logs => _logs;

  List<String> getAvailablePorts() {
    return SerialPort.availablePorts;
  }

  Future<bool> connect(String portName, {int baudRate = 115200}) async {
    try {
      _port = SerialPort(portName);
      if (!_port!.openReadWrite()) {
        _log("SYSTEM ERROR: Failed to open port $portName");
        return false;
      }
      
      // 配置串口波特率与帧格式
      SerialPortConfig config = _port!.config;
      config.baudRate = baudRate;
      config.bits = 8;
      config.stopBits = 1;
      config.parity = SerialPortParity.none;
      _port!.config = config;

      _isConnected = true;
      _log("CONNECTED TO SYSTEM ON $portName @ $baudRate");

      // 开启异步监听循环
      _reader = SerialPortReader(_port!);
      _reader!.stream.listen(_handleIncomingRawData, onError: (err) {
        _log("RX ERROR: $err");
        disconnect();
      });

      notifyListeners();
      return true;
    } catch (e) {
      _log("CONNECTION EXCEPTION: $e");
      return false;
    }
  }

  void _handleIncomingRawData(Uint8List data) {
    String chunk = utf8.decode(data, allowMalformed: true);
    // 行缓冲拼接逻辑
    _buffer += chunk;
    int lineEnd;
    while ((lineEnd = _buffer.indexOf('\n')) >= 0) {
      String line = _buffer.substring(0, lineEnd).trim();
      _buffer = _buffer.substring(lineEnd + 1);
      if (line.isNotEmpty) {
        _lineStreamController.add(line);
        _log(line);
      }
    }
  }

  String _buffer = "";

  Future<void> sendCommand(String cmd) async {
    if (!_isConnected || _port == null) return;
    try {
      final bytes = utf8.encode("$cmd\n");
      _port!.write(Uint8List.fromList(bytes));
      _log("> $cmd");
    } catch (e) {
      _log("TX ERROR: $e");
    }
  }

  void disconnect() {
    if (!_isConnected) return;
    _reader?.close();
    _port?.close();
    _isConnected = false;
    _log("DISCONNECTED FROM SYSTEM PORT");
    notifyListeners();
  }

  void _log(String msg) {
    _logs.add(msg);
    if (_logs.length > 500) _logs.removeAt(0); // 限制缓冲区大小
    notifyListeners();
  }
}
```

---

## 4. 蒸汽波 UI 设计规范与实现

### 4.1 颜色系统 (`lib/constants/colors.dart`)

```dart
import 'package:flutter/material.dart';

class VaporColors {
  static const Color bgDark = Color(0xFF0A0712);      // 深邃太空黑
  static const Color neonPink = Color(0xFFFF4FD8);    // 极光粉
  static const Color neonCyan = Color(0xFF2BE4FF);    // 霓虹青
  static const Color accentPurple = Color(0xFF8A4FFF); // 迷幻紫
  static const Color sunsetOrange = Color(0xFFFF9E57); // 晚霞橙
  static const Color gridLine = Color(0xFF2D2142);     // 网格暗紫
  static const Color textColor = Color(0xFFE8E8F0);    // 亮荧光白
}
```

### 4.2 3D 透视滚屏网格的 Flutter 实现 (`lib/widgets/neon_grid.dart`)

利用 `Transform` 矩阵组件进行 X 轴偏转，并在 `AnimationController` 中刷新贴图偏移，创造复古 3D 赛博空间感：

```dart
import 'package:flutter/material.dart';
import '../constants/colors.dart';

class NeonGridWidget extends StatefulWidget {
  const NeonGridWidget({Key? key}) : super(key: key);

  @override
  State<NeonGridWidget> createState() => _NeonGridWidgetState();
}

class _NeonGridWidgetState extends State<NeonGridWidget> with SingleTickerProviderStateMixin {
  late AnimationController _controller;

  @override
  void initState() {
    super.initState();
    _controller = AnimationController(
      vsync: this,
      duration: const Duration(seconds: 4),
    )..repeat();
  }

  @override
  void dispose() {
    _controller.dispose();
    super.dispose();
  }

  @override
  Widget build(BuildContext context) {
    return AnimatedBuilder(
      animation: _controller,
      builder: (context, child) {
        return Transform(
          transform: Matrix4.identity()
            ..setEntry(3, 2, 0.003) // 透视矩阵投影
            ..rotateX(1.15),       // 绕X轴翻转，形成地平线视角
          alignment: Alignment.bottomCenter,
          child: Container(
            width: double.infinity,
            height: 350,
            decoration: BoxDecoration(
              gradient: LinearGradient(
                begin: Alignment.topCenter,
                end: Alignment.bottomCenter,
                colors: [
                  VaporColors.bgDark,
                  VaporColors.accentPurple.withOpacity(0.15),
                ],
              ),
            ),
            child: CustomPaint(
              painter: _GridLinePainter(_controller.value),
            ),
          ),
        );
      },
    );
  }
}

class _GridLinePainter extends CustomPainter {
  final double progress;
  _GridLinePainter(this.progress);

  @override
  void paint(Canvas canvas, Size size) {
    final paint = Paint()
      ..color = VaporColors.accentPurple.withOpacity(0.2)
      ..strokeWidth = 1.0;

    // 绘制纵向射线网格
    const int linesCount = 20;
    for (int i = 0; i <= linesCount; i++) {
      double x = (size.width / linesCount) * i;
      canvas.drawLine(Offset(x, 0), Offset(x, size.height), paint);
    }

    // 绘制横向滚屏横线
    double step = 40.0;
    double offset = progress * step;
    for (double y = offset; y < size.height; y += step) {
      canvas.drawLine(Offset(0, y), Offset(size.width, y), paint);
    }
  }

  @override
  bool shouldRepaint(covariant _GridLinePainter oldDelegate) => true;
}
```

### 4.3 CRT 扫描线与闪烁滤镜效果 (`lib/widgets/crt_screen.dart`)

为整个应用包裹一个 CRT 噪点扫描滤镜：

```dart
import 'dart:math';
import 'package:flutter/material.dart';

class CrtFilterWidget extends StatelessWidget {
  final Widget child;
  const CrtFilterWidget({Key? key, required this.child}) : super(key: key);

  @override
  Widget build(BuildContext context) {
    return Stack(
      children: [
        child,
        // CRT 扫描线叠加层
        IgnorePointer(
          child: Container(
            decoration: const BoxDecoration(
              image: DecorationImage(
                image: AssetImage('assets/images/scanlines.png'), // 或者使用 CustomPaint 绘制
                repeat: ImageRepeat.repeat,
                opacity: 0.1,
              ),
            ),
          ),
        ),
        // 动态 CRT 横向扫描亮线动画
        const IgnorePointer(
          child: _CrtScanLineAnimation(),
        ),
      ],
    );
  }
}

class _CrtScanLineAnimation extends StatefulWidget {
  const _CrtScanLineAnimation({Key? key}) : super(key: key);

  @override
  State<_CrtScanLineAnimation> createState() => _CrtScanLineAnimationState();
}

class _CrtScanLineAnimationState extends State<_CrtScanLineAnimation> with SingleTickerProviderStateMixin {
  late AnimationController _controller;

  @override
  void initState() {
    super.initState();
    _controller = AnimationController(
      vsync: this,
      duration: const Duration(seconds: 8),
    )..repeat();
  }

  @override
  void dispose() {
    _controller.dispose();
    super.dispose();
  }

  @override
  Widget build(BuildContext context) {
    return AnimatedBuilder(
      animation: _controller,
      builder: (context, child) {
        return Positioned(
          top: _controller.value * MediaQuery.of(context).size.height,
          left: 0,
          right: 0,
          height: 6,
          child: Container(
            decoration: BoxDecoration(
              gradient: LinearGradient(
                begin: Alignment.topCenter,
                end: Alignment.bottomCenter,
                colors: [
                  Colors.transparent,
                  Colors.white.withOpacity(0.06),
                  Colors.transparent,
                ],
              ),
            ),
          ),
        );
      },
    );
  }
}
```

---

## 5. UI 架构与控制交互

### 5.1 ASCII 风格仪表盘组件示例

```dart
class TelemetryBar extends StatelessWidget {
  final String label;
  final double value;
  final double max;

  const TelemetryBar({required this.label, required this.value, required this.max});

  @override
  Widget build(BuildContext context) {
    final int barsCount = 20;
    double progress = (value / max).clamp(0.0, 1.0);
    int filledCount = (progress * barsCount).round();
    
    String bar = '[' + '█' * filledCount + '░' * (barsCount - filledCount) + ']';

    return Text(
      "$label: $bar ${(progress * 100).toStringAsFixed(0)}%",
      style: GoogleFonts.ibmPlexMono(
        color: VaporColors.neonCyan,
        fontSize: 13,
        fontWeight: FontWeight.bold,
        shadows: [
          const Shadow(
            color: VaporColors.neonCyan,
            blurRadius: 8,
          ),
        ],
      ),
    );
  }
}
```

### 5.2 发送限制滑块 (Debounced PWM Slider)

为了防止快速滑动 Slider 时产生海量 I2C 报文导致系统卡死，需要在 Dart 中对串口发送函数进行防抖/节流限制：

```dart
import 'dart:async';
import 'package:flutter/material.dart';

class PwmControlSlider extends StatefulWidget {
  final String title;
  final Function(int) onPwmChanged;
  
  const PwmControlSlider({required this.title, required this.onPwmChanged});

  @override
  State<PwmControlSlider> createState() => _PwmControlSliderState();
}

class _PwmControlSliderState extends State<PwmControlSlider> {
  double _currentValue = 0;
  Timer? _throttleTimer;

  void _onSliderValueUpdated(double val) {
    setState(() {
      _currentValue = val;
    });

    // 节流处理：限制发送频率为每 60 毫秒一次 (约 16Hz)
    if (_throttleTimer == null || !_throttleTimer!.isActive) {
      _throttleTimer = Timer(const Duration(milliseconds: 60), () {
        widget.onPwmChanged(_currentValue.toInt());
      });
    }
  }

  @override
  Widget build(BuildContext context) {
    return Column(
      crossAxisAlignment: CrossAxisAlignment.start,
      children: [
        Row(
          justifyAxisAlignment: MainAxisAlignment.between,
          children: [
            Text(widget.title, style: TextStyle(color: VaporColors.sunsetOrange, fontSize: 11)),
            Text("${_currentValue.toInt()}", style: TextStyle(color: VaporColors.neonPink)),
          ],
        ),
        SliderTheme(
          data: SliderTheme.of(context).copyWith(
            thumbColor: VaporColors.neonPink,
            activeTrackColor: VaporColors.neonCyan,
            inactiveTrackColor: VaporColors.gridLine,
          ),
          child: Slider(
            value: _currentValue,
            min: -1000,
            max: 1000,
            onChanged: _onSliderValueUpdated,
          ),
        ),
      ],
    );
  }
}
```

---

## 6. 音效包集成

借助 `soundpool` 库，在串口动作或键盘按下时播放复古音效：

```dart
import 'package:flutter/services.dart';
import 'package:soundpool/soundpool.dart';

class SoundEffectsManager {
  static Soundpool? _pool;
  static int? _clickSoundId;
  static int? _bootSoundId;

  static Future<void> init() async {
    _pool = Soundpool.fromOptions(options: const SoundpoolOptions(maxStreams: 4));
    
    // 加载资源中的短音频
    _clickSoundId = await rootBundle.load("assets/sounds/click.wav").then((ByteData soundData) {
      return _pool!.load(soundData);
    });
    _bootSoundId = await rootBundle.load("assets/sounds/boot.wav").then((ByteData soundData) {
      return _pool!.load(soundData);
    });
  }

  static void playClick() {
    if (_pool != null && _clickSoundId != null) {
      _pool!.play(_clickSoundId!);
    }
  }

  static void playBoot() {
    if (_pool != null && _bootSoundId != null) {
      _pool!.play(_bootSoundId!);
    }
  }
}
```

---

## 7. 桌面端 (Linux/Fedora) 构建步骤

要在 Linux 端正常开发和构建此 App，需要配置串口 C 库的本地编译环境：

1.  **安装 Linux 底层 C 依赖库**：
    在 Fedora 系统上，执行以下命令安装 `libserialport` 开发包：
    ```bash
    sudo dnf install libserialport-devel clang make pkg-config gtk3-devel
    ```
2.  **启用 Linux 桌面端开发**：
    ```bash
    flutter config --enable-linux-desktop
    ```
3.  **运行程序**：
    ```bash
    flutter run -d linux
    ```
4.  **打包 Release 可执行文件**：
    ```bash
    flutter build linux --release
    ```
    构建产物将输出在 `build/linux/x64/release/bundle/` 中，可直接解压运行。

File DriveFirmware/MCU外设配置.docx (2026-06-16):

# UART

1.配置为异步通信（Asynchronous）,波特率、字长、奇偶检验位与停止位根据需要选择（这里保持默认），其他如高级配置参数保持默认。

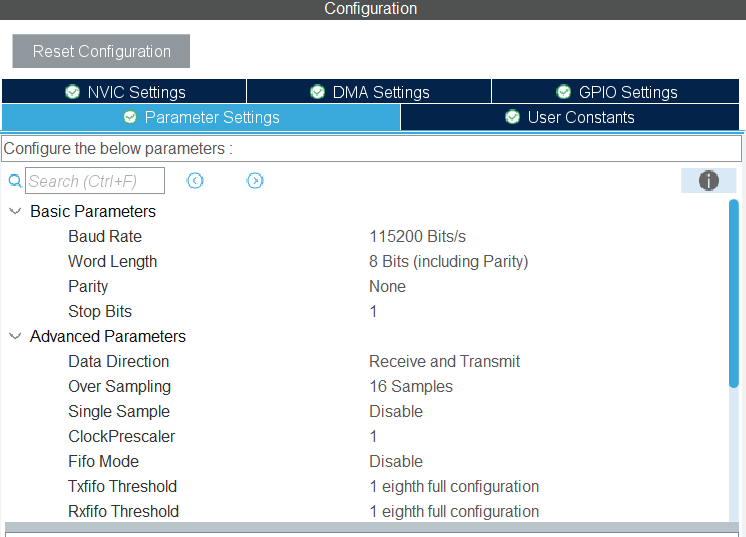
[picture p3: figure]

2.使用中断回调函数，进行收发完成事件的处理逻辑

void HAL_UART_TxCpltCallback(UART_HandleTypeDef *huart);（此项目仅用于发送完成指示灯）

void HAL_UART_RxCpltCallback(UART_HandleTypeDef *huart);（处理上位机发送的字符指令）

因为使用到中断功能，注意勾选USART global interupt

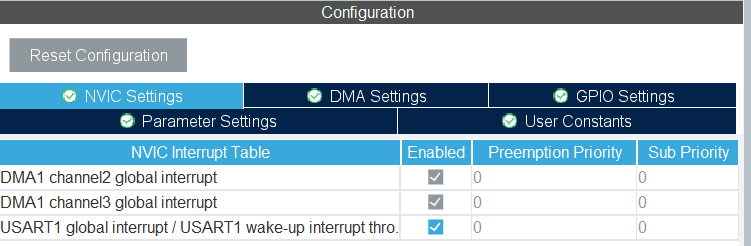
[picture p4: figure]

3. 为了节省CPU运算资源，采用DMA(直接内存访问)进行收发操作

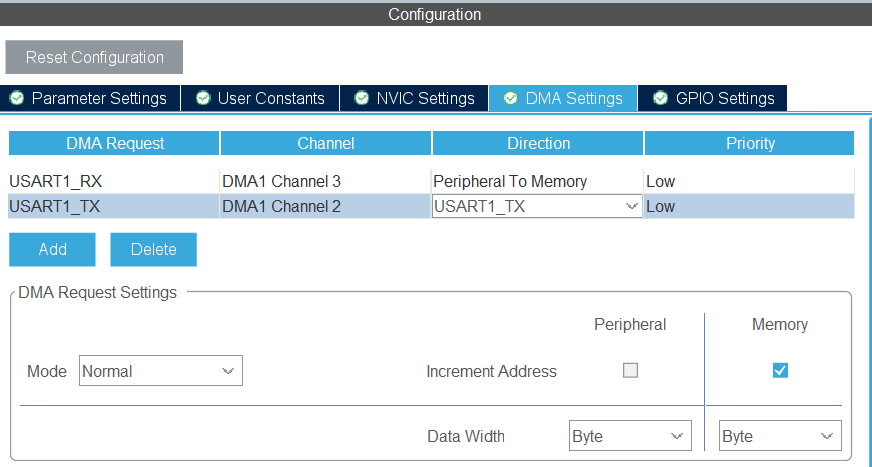
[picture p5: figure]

对内存勾选地址自增，外设移位寄存器不需要

DMA同样需要使用中断功能，同样注意勾选NVIC,USART global interupt

发送数据

注意将发送/接收数据缓冲区buffer设置为静态变量（static）以进行稳定的串口通信

（此为经验之谈）

static float data[6];static uint8_t tail[4]={0x00,0x00,0x80,0x7f};

static uint8_t buffer[sizeof(float)*6 + sizeof(tail)];

memcpy(buffer, data, sizeof(float)*6);

memcpy(buffer + sizeof(float)*6, tail, sizeof(tail));

HAL库封装USART_DMA发送函数：

HAL_UART_Transmit_DMA(&huart1, buffer, sizeof(buffer));（结束后进入TxCpltCallback中断）

HAL_UART_Receive_DMA(&huart1, buffer, sizeof(buffer));（结束后进入RxCpltCallback中断）

接收数据

由于从VOFA+上位机接收到的指令数据难免不定长，故使用

HAL_UARTEx_ReceiveToIdle_DMA(&huart1,buffer_Rx,sizeof(buffer_Rx));

对应的中断回调函数

void HAL_UART_ErrorCallback(UART_HandleTypeDef *huart)

{

if (huart == &huart1)

{

HAL_UARTEx_ReceiveToIdle_DMA(&huart1, buffer_receive, sizeof(buffer_receive));

}

}

对应的错误处理函数

void HAL_UART_ErrorCallback(UART_HandleTypeDef *huart)

{

if (huart == &huart1)

{

HAL_UARTEx_ReceiveToIdle_DMA(&huart1, buffer_receive, sizeof(buffer_receive));

}

}

4. 本项目使用TIM3基本定时器以固定频率与上位机通信

时钟源：Internal clock（实际上为TIM3挂载的APB总线时钟）

HAL_TIM_Base_Start_IT(&htim3);(开启TIM3计数与中断)

根据通信频率需要，配置预分频，与计数周期（ARR）

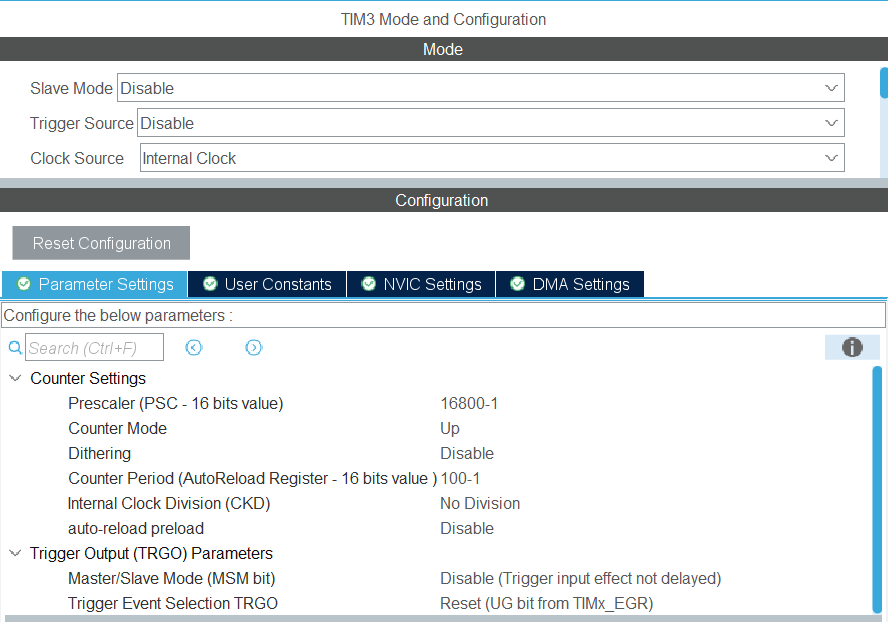
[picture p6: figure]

# Advance TIM1

此高级定时器用于配置互补PWM输出，以及TIM1_CH4触发ADC采样

时钟源：Internal clock

三对互补PWM输出以及ADC触发采样通道

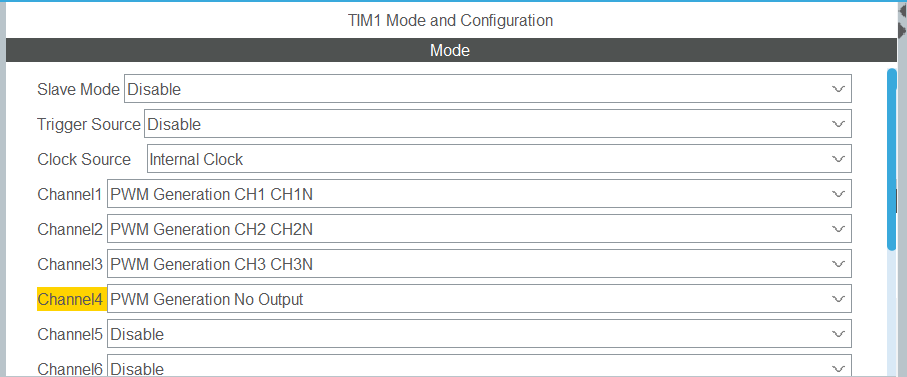
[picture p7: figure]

由于采样通道通过中断触发ADC采样，须使能TIM1 NVIC中断

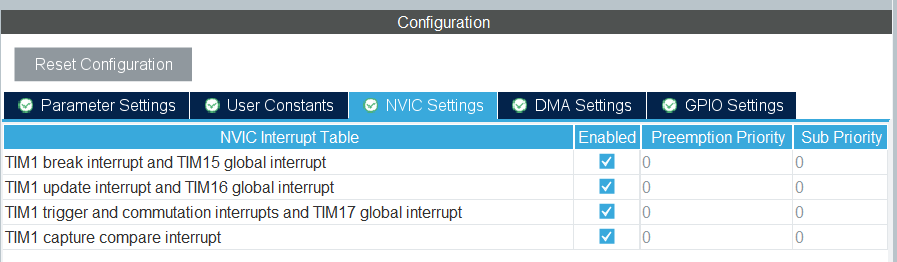
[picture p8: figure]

预分频系数以及自动重装载值（ARR也叫计数周期）根据所需PWM发波频率结合APB总线时钟进行配置

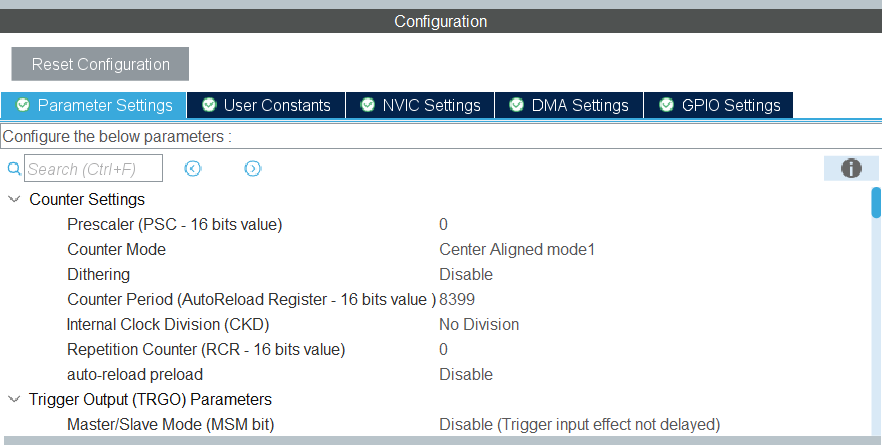
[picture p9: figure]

死区时间根据实际MOS硬件需要进行配置（有待深入研究）

（防止上下MOS同时导通手段：死区时间设置，栅极电阻反向并联二极管）

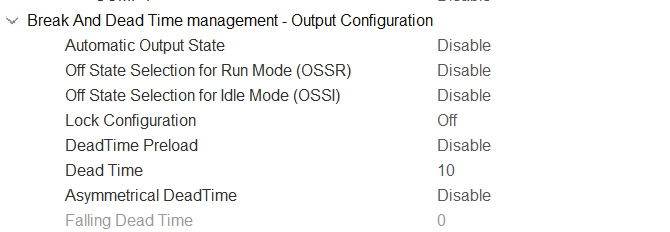
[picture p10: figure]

三路互补PWM设置为PWM mode 1（计数值小于CCR时输出高）

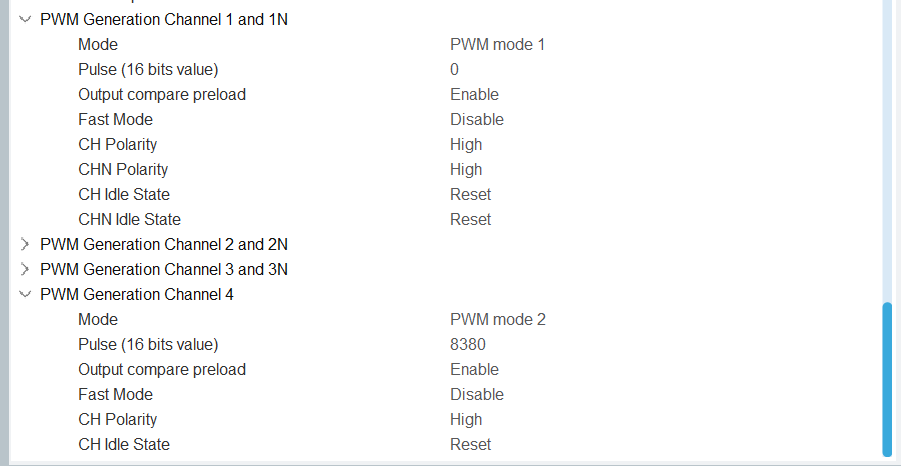
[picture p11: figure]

采用 __HAL_TIM_SET_COMPARE(&htim1, TIM_CHANNEL_1, pulse_value);函数实时设置CCR

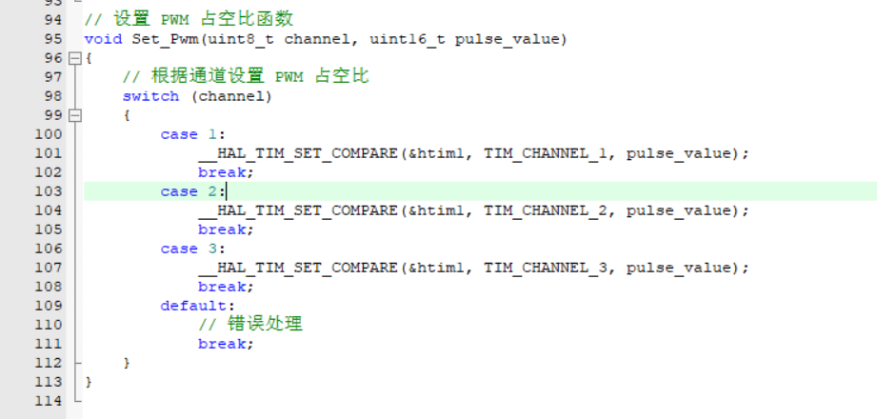
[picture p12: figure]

使能三路互补PWM输出，并设置TIM1_CH4采样通道的CCR为TIM1_ARR-10

HAL_TIM_Base_Start(&htim1);

HAL_TIM_PWM_Start(&htim1,TIM_CHANNEL_4);

__HAL_TIM_SET_COMPARE(&htim1,TIM_CHANNEL_4,__HAL_TIM_GET_AUTORELOAD(&htim1)- 10);

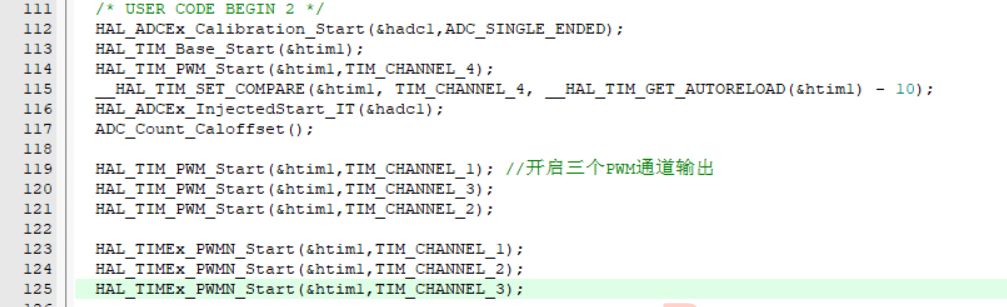
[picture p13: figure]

# ADC

设置为单个ADC内的多通道采样

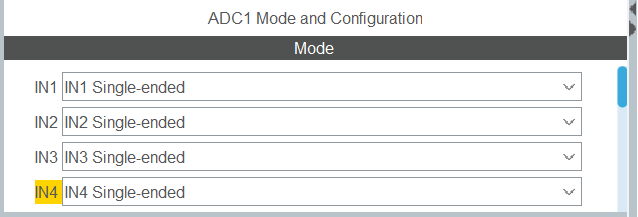
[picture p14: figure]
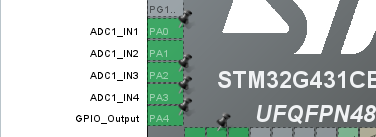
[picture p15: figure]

开启扫描模式

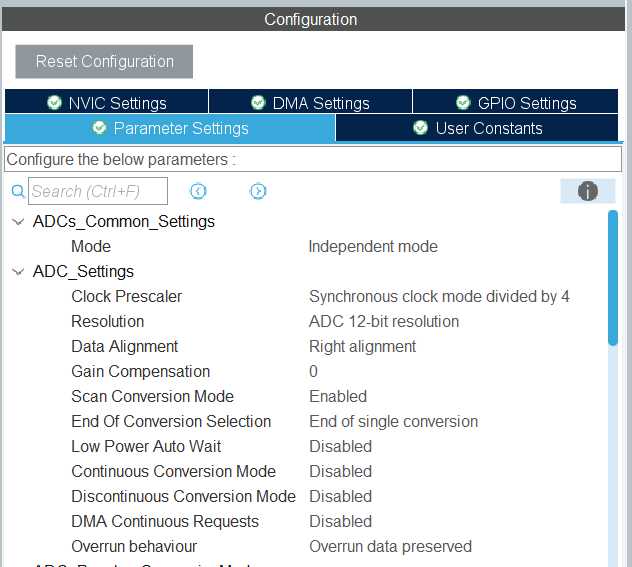
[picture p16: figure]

开启注入组转换模式，设置Conversion次数，并设置外部触发源为TIM1的CH4触发

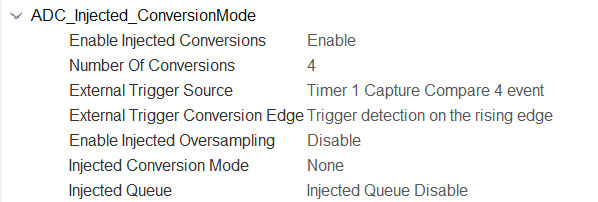
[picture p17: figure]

设置采样Rank 1~4分别对应ADC1哪个通道

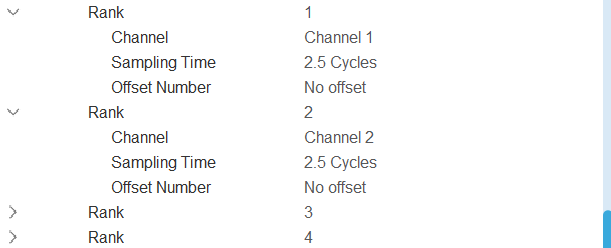
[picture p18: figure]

由于采样完成后会触发注入组采样完成中断，故使能ADC1 global interupt

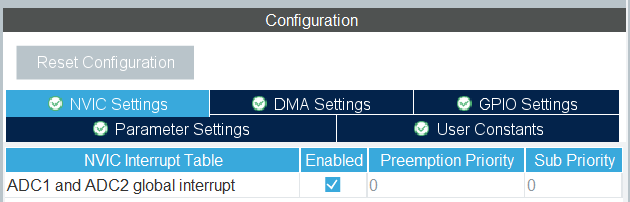
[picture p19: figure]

采样执行前对ADC进行标定

HAL_ADCEx_Calibration_Start(&hadc1,ADC_SINGLE_ENDED);

并使能注入组中断

HAL_ADCEx_InjectedStart_IT(&hadc1);

注入组转换完成中断回调函数，处理转换数据

void HAL_ADCEx_InjectedConvCpltCallback(ADC_HandleTypeDef* hadc)

{

if (hadc->Instance == ADC1)

{

adc_value_in1 = HAL_ADCEx_InjectedGetValue(hadc, ADC_INJECTED_RANK_1);

ia=(adc_value_in1-bias_ia)*0.00161132f;

adc_value_in2 = HAL_ADCEx_InjectedGetValue(hadc, ADC_INJECTED_RANK_2);

ib=(adc_value_in2-bias_ib)*0.00161132f;

adc_value_in3 = HAL_ADCEx_InjectedGetValue(hadc, ADC_INJECTED_RANK_3);

ic=(adc_value_in3-bias_ic)*0.00161132f;

adc_value_in4 = HAL_ADCEx_InjectedGetValue(hadc, ADC_INJECTED_RANK_4);

vbus=(adc_value_in4-bias_vbus)*0.00007324;

}

}

须注意程序执行前，在Ia、Ib、Ic三路电流为0时，进行零电流值补偿值计算

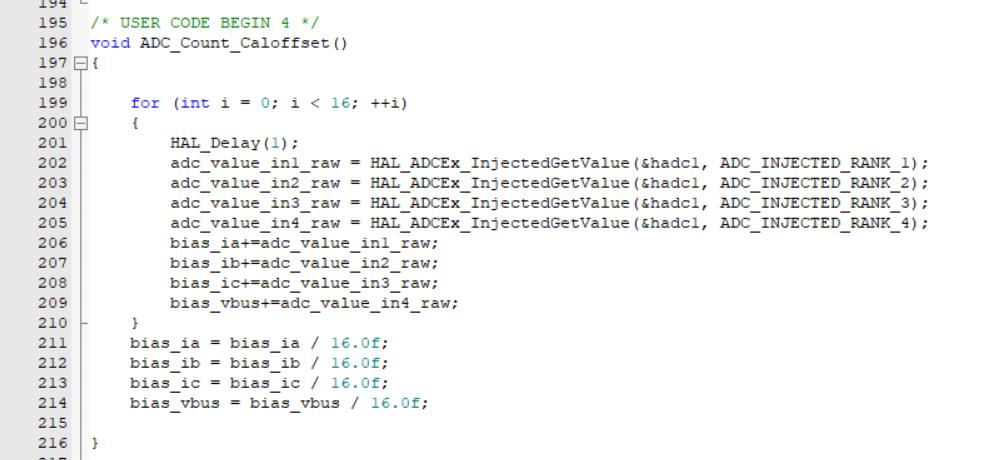
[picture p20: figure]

# SPI通信

本项目SPI用于与MT6816磁编码器进行通信

配置好引脚

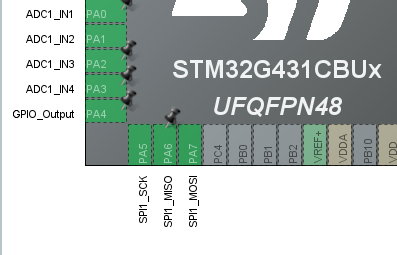
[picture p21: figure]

基本参数设置，片选信号设置为软件片选

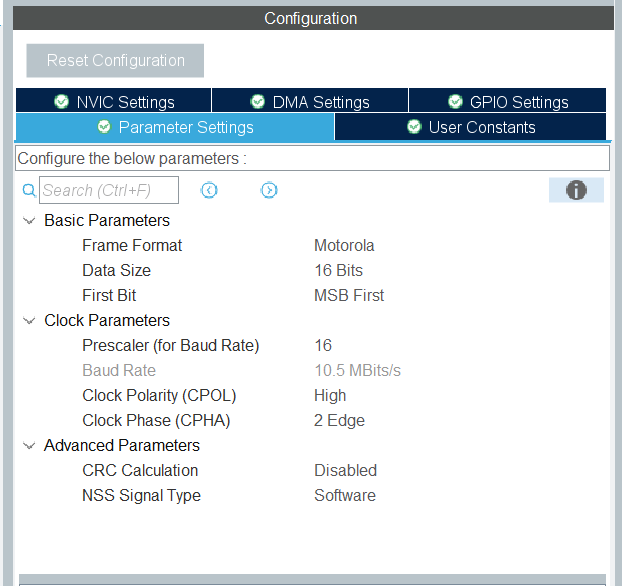
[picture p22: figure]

目前没用到SPI中断但我还是先开了

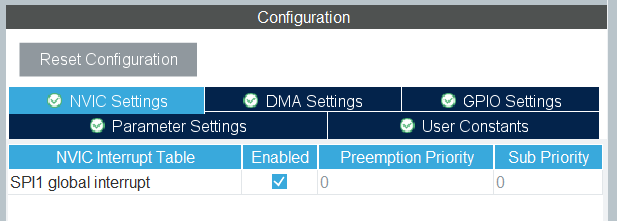
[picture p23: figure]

软件拉高拉低片选引脚函数宏

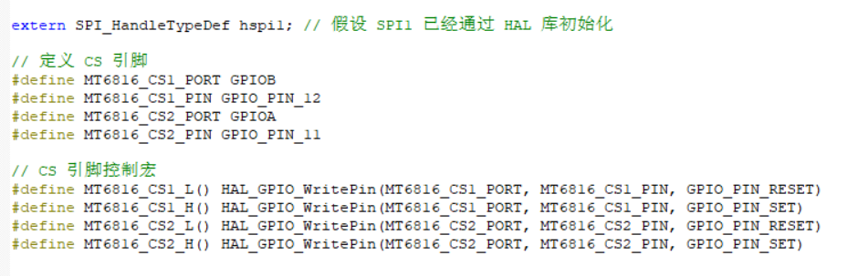
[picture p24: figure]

SPI初始化

MT6816_SPI_Signal_Typedef mt6816_spi;

void MT6816_SPI_Signal_Init(void) {

mt6816_spi.sample_data = -1;

mt6816_spi.angle = -1;

SPI1->CR1 |= SPI_CR1_SPE;

}

根据数据手册，写通信协议

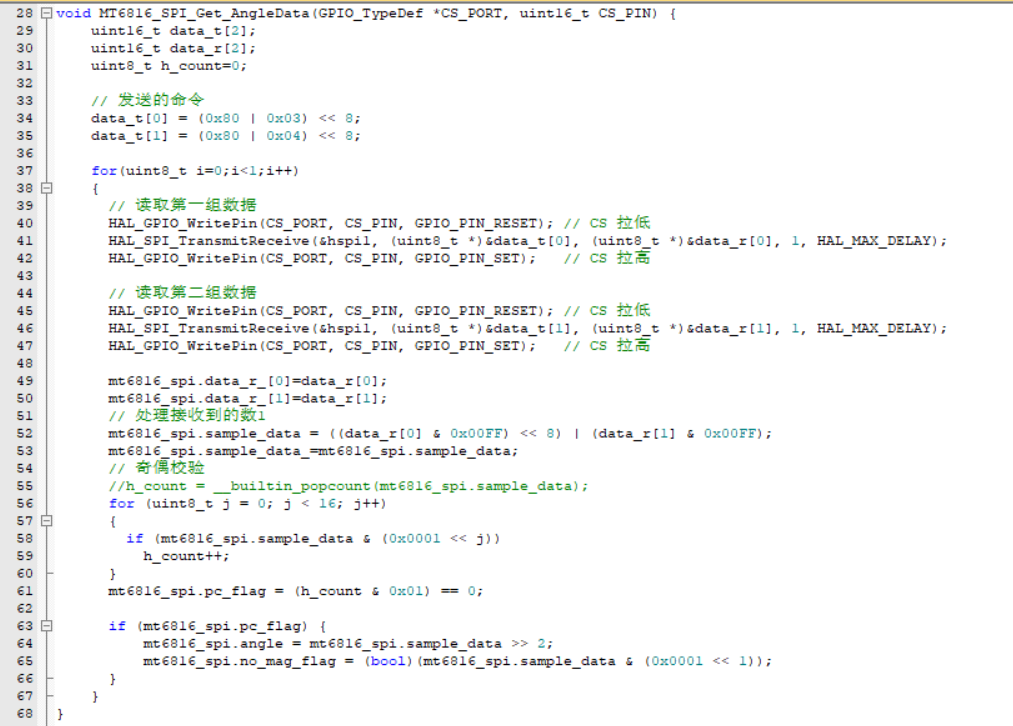
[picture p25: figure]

HAL库封装SPI收发函数

HAL_SPI_TransmitReceive(&hspi1, (uint8_t *)&data_t[0], (uint8_t *)&data_r[0], 1, HAL_MAX_DELAY);

# TIM4

TIM4 通用定时器用于精准的时间戳获取

本系统APB1总线时钟频率为168MHZ,为了使每次计数为1us,直接调整预分频系数168

为了使系统工作时间最大，计数周期设置为了0xFFFF

经过计算，如果使用uint32_t类型存储溢出计数，本系统的工作时间约为71.58分钟

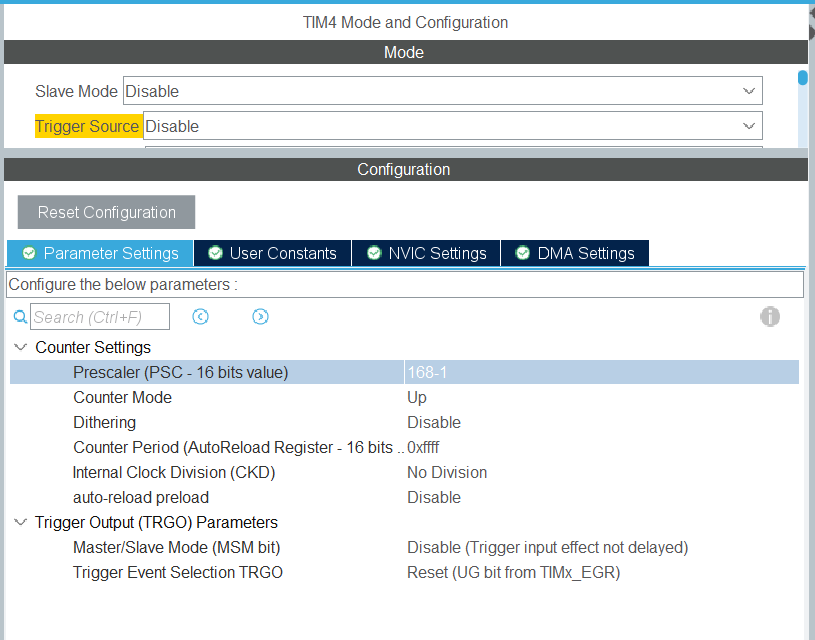
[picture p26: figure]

由于将会在计数溢出中断处理函数中将current_count++,故开启TIM4的NVIC

并在主程序中开启TIM4中断

HAL_TIM_Base_Start_IT(&htim4);

获取微秒级时间函数

uint32_t Get_Timestamp_us(void)

{

uint32_t timestamp = 0;

uint32_t current_count;

__disable_irq();消除中断干扰

current_count = __HAL_TIM_GET_COUNTER(&htim4);

timestamp = (overflow_count * 0xFFFF + current_count); // 1MHz

__enable_irq();

return timestamp;

}

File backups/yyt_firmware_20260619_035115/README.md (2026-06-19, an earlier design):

# YYT Firmware Backup 20260619_035115

This backup was created before moving toward a unified bring-up firmware set for the wheel-leg robot.

Contents:

- `DriveFirmware_snapshot/`: full local snapshot of the current `DriveFirmware` directory, including build outputs.
- `YYT_MiniOdrive_open_source_snapshot/`: snapshot of the referenced open-source firmware folder used during diagnosis.
- `tools_snapshot/yyt_drive_uart_debug.py`: UART debug console script.
- `worktree_tracked.diff`: tracked-file diff for the current worktree at backup time.
- `id5_board_flash_0x08000000_128k.bin`: raw 128 KiB flash dump from the currently connected ID5 drive board.
- `id1_before_unified/`: raw ID1 board flash backup made before refreshing ID1.
- `id1_refreshed_unified/`: copy of the unified ID1 firmware flashed after the ID1 backup.
- `id2_before_unified/`: raw ID2 board flash backup made before refreshing ID2.
- `id2_refreshed_unified/`: copy of the unified ID2 firmware flashed after the ID2 backup.
- `id5_refreshed_unified/`: copy of the unified ID5 firmware flashed after the earlier ID5 UART/debug tuning builds.
- `id6_power_on_zero_hold/`: raw ID6 board flash backup named `上电自动保持零位`.
- `id6_refreshed_unified/`: copy of the unified ID6 firmware flashed after the backup.

Known ID5 diagnostic state at backup time:

- Drive ID: 5
- UART debug firmware enabled
- Auto zero hold disabled
- UART/SWD debug voltage limit raised to 6 V
- Boot sweep skipped for ID5 UART debug build
- Position-loop test direction: `sign=+1`
- Last tested stable small-step direction: target angle increased and measured angle moved in the correct direction

Restore ID5 raw board flash with ST-Link:

```sh
cd /Users/ylris/轮腿/ParallelLegRobot/DriveFirmware
openocd -f interface/stlink.cfg -f target/stm32g4x.cfg -c "adapter speed 100; program ../backups/yyt_firmware_20260619_035115/id5_board_flash_0x08000000_128k.bin 0x08000000 verify reset exit"
```

Restore ID1 raw board flash with ST-Link:

```sh
cd /Users/ylris/轮腿/ParallelLegRobot/DriveFirmware
openocd -f interface/stlink.cfg -f target/stm32g4x.cfg -c "adapter speed 100; program ../backups/yyt_firmware_20260619_035115/id1_before_unified/id1_board_flash_0x08000000_128k.bin 0x08000000 verify reset exit"
```

Restore ID2 raw board flash with ST-Link:

```sh
cd /Users/ylris/轮腿/ParallelLegRobot/DriveFirmware
openocd -f interface/stlink.cfg -f target/stm32g4x.cfg -c "adapter speed 100; program ../backups/yyt_firmware_20260619_035115/id2_before_unified/id2_board_flash_0x08000000_128k.bin 0x08000000 verify reset exit"
```

ID1, ID2, ID5, and ID6 board flash backups have been read out in this backup set.

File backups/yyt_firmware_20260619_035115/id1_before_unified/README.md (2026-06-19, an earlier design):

# ID1 Firmware Backup

This is a raw flash dump from the ID1 YYT drive board before refreshing it to the unified main-controller-driven firmware.

Backup file:

- `id1_board_flash_0x08000000_128k.bin`

Backup details:

- Board: ID1 YYT MiniOdrive drive board
- Address: `0x08000000`
- Size: `0x20000` bytes / 128 KiB
- SHA256: `c832d74ba2b95694cfbcc2e81a691490b01550b9779125c34cd6162136773dfb`
- Backup time context: immediately before flashing ID1 unified firmware

Restore command:

```sh
cd /Users/ylris/轮腿/ParallelLegRobot/DriveFirmware
openocd -f interface/stlink.cfg -f target/stm32g4x.cfg -c "adapter speed 100; program ../backups/yyt_firmware_20260619_035115/id1_before_unified/id1_board_flash_0x08000000_128k.bin 0x08000000 verify reset exit"
```

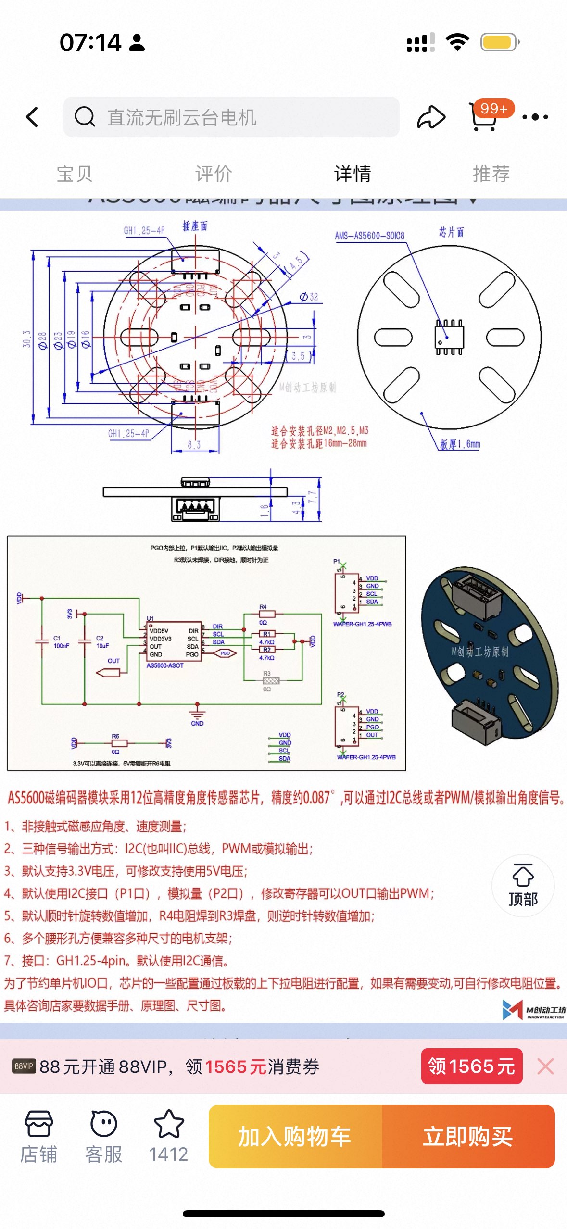
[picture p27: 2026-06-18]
docs/0499A78567F1A28A08F3065C2EA0253B.jpg

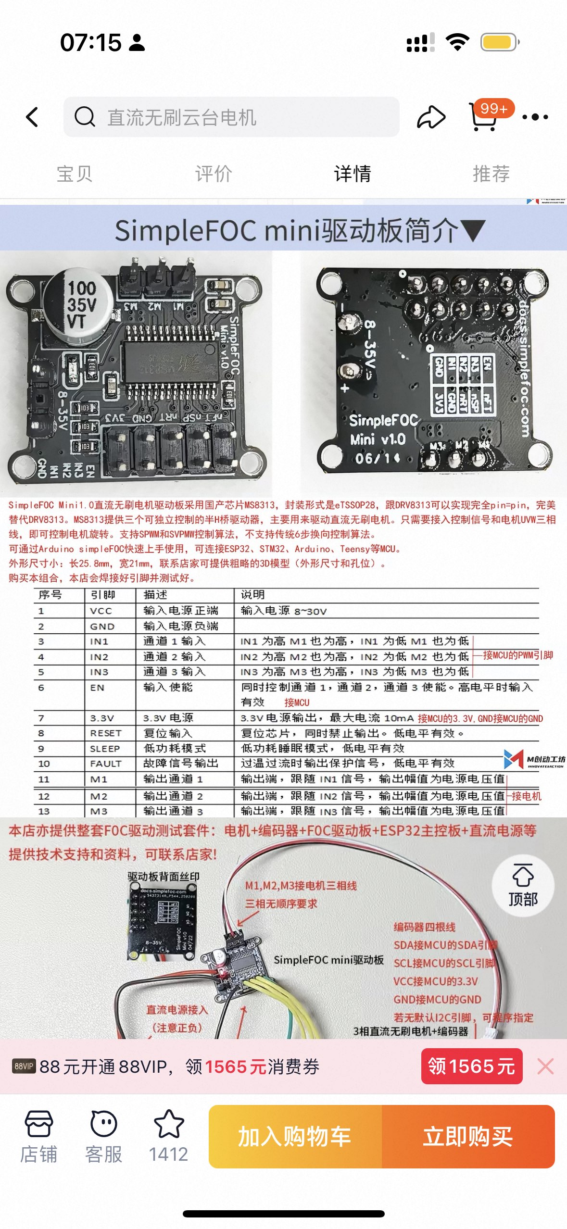
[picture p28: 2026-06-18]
docs/FE2BFD12326B847923B681BDD27FDFC7.jpg

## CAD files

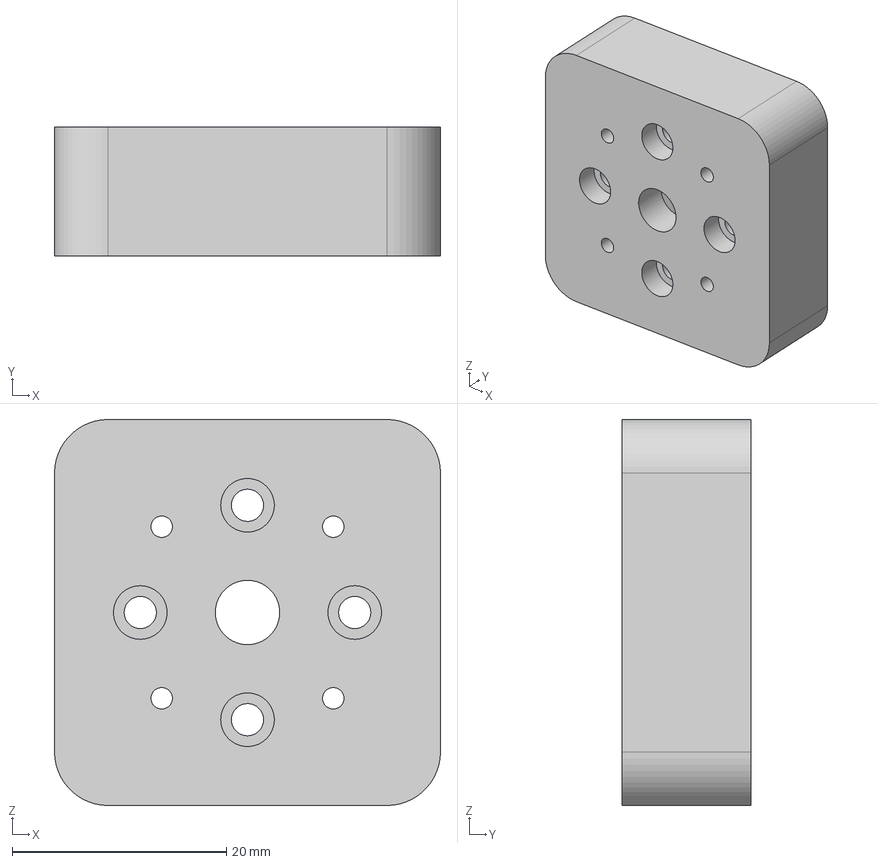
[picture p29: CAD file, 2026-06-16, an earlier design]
backups/yyt_firmware_20260619_035115/YYT_MiniOdrive_open_source_snapshot/设计文件/PM3510拉马.step
36.0 x 12.0 x 36.0 mm

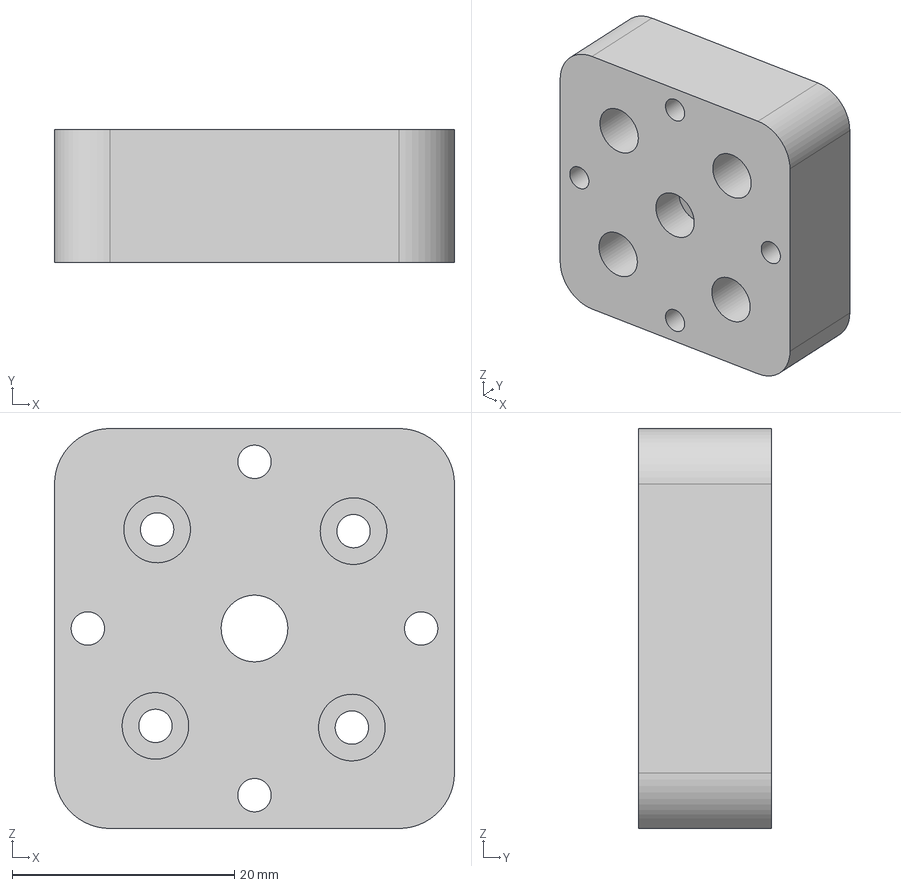
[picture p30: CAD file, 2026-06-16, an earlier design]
backups/yyt_firmware_20260619_035115/YYT_MiniOdrive_open_source_snapshot/设计文件/4310云台电机拉马.step
36.0 x 12.0 x 36.0 mm

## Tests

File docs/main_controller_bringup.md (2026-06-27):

# ESP32C3 主控安全联调流程

本文档对应默认固件 `src/main.cpp`，目标是在轮电机闭环尚未接入、四个腿电机架空时，先完成腿部 CAN 控制链路。

## 当前硬件连接

- 自制主控板 CAN+ 接 YYT 驱动 CANH。
- 自制主控板 CAN- 接 YYT 驱动 CANL。
- 自制主控板 ESP32C3 逻辑侧 CAN_RX 为 GPIO7，CAN_TX 为 GPIO6。
- YYT 电机 ID 按侧视图/图面坐标记录：
  - 图面左上腿关节：ID1
  - 图面左下腿关节：ID2
  - 图面右上腿关节：ID5
  - 图面右下腿关节：ID6
  - 左腿轮电机：ID3
  - 右腿轮电机：ID4

## 固件安全策略

- 当前构建上电 `disarmed`，默认命令为 0 mV，不会主动点动或自动保持姿态。
- 需要通过 `arm` 显式允许腿电机输出电压。
- `test` 只允许 ID1/2/5/6，持续时间限制为 20 到 500 ms。当前非零点动电压会限制到 `+/-6000..12000 mV`。
- `height` 高度保持必须先完成 ID1/2/5/6 四个关节的 `test` 点动，再输入 `confirm_dirs`。
- 如果某个关节方向反了，可以先用 `invert <id>` 临时翻转，或者用 `sign <id> <1|-1>` 指定方向；修改方向后需要重新点动确认。
- 任一腿电机离线、关节超过软限位、CAN 发送失败、CAN 总线错误、或者 `disarm/stop`，高度保持都会停止并清零输出。

## 编译和烧录

```sh
cd /Users/ylris/轮腿/ParallelLegRobot
pio run -e esp32-c3-devkitm-1
pio run -e esp32-c3-devkitm-1 -t upload --upload-port /dev/cu.usbmodem1301
```

如果端口不是 `/dev/cu.usbmodem1301`，先查：

```sh
ls /dev/cu.usbmodem* /dev/cu.usbserial* 2>/dev/null
```

## 串口查看

```sh
pio device monitor -p /dev/cu.usbmodem1301 -b 115200
```

正常启动后会周期性看到：

```text
online: ID1=yes ID2=yes ID5=yes ID6=yes armed=no hold=off
```

输入：

```text
can
status
```

`can` 正常应看到 `state=running`，`tx_fail=0`。`status` 正常时能看到四个电机的 `raw` 原始角度和 `q` 零点归一角度。零点姿态附近，`q` 应接近 0 rad。

输入：

```text
dirs
```

可以看到方向检查提示和四个关节当前 `q` 值。这个命令只读数，不会让电机动作。
其中 `tested=yes/no` 表示这个关节是否已经在当前上电周期执行过 `test`。只有四个关节都是 `tested=yes`，`confirm_dirs` 才会通过。

## 单关节点动

先确保：

- 四个腿电机架空。
- 手能马上关闭实验电源。
- 限流先保守。
- 串口状态四个 ID 都在线。

推荐先用脚本辅助，它会在每个电机点动前暂停，按回车才继续，并在最后汇总四个 `dq`：

```sh
cd /Users/ylris/轮腿/ParallelLegRobot
python3 tools/leg_test_sequence.py --port /dev/cu.usbmodem1301
```

脚本会自动把完整输出保存到 `logs/leg_test_时间.txt`。如果想指定日志文件：

```sh
python3 tools/leg_test_sequence.py --port /dev/cu.usbmodem1301 --log logs/my_leg_test.txt
```

`logs/*.txt` 默认被 `.gitignore` 忽略，作为本地现场证据保存。需要分析时，把日志路径或内容发出来即可。

如果要全自动不暂停，可以加 `--yes`，但首次不建议。

也可以手动在串口输入：

串口输入：

```text
arm
test 1 6000 100
stop
```

观察 ID1 是否轻微动一下，电流是否异常。`test` 结束后会打印 `q_before`、`q_after`、`dq`，把 `dq` 的正负记下来。然后依次测：

```text
test 2 6000 100
test 5 6000 100
test 6 6000 100
```

如果方向反了，先不要输入 `confirm_dirs`。例如 ID2 方向反了，输入：

```text
invert 2
test 2 6000 100
```

也可以直接指定方向：

```text
sign 2 -1
test 2 6000 100
```

注意：这个方向修改是运行时临时修改，重启后会恢复固件默认值。等四个方向都确认稳定后，再把最终 sign 固化进代码。
每次 `invert` 或 `sign` 后，该 ID 的 `tested` 会回到 `no`，必须重新 `test`。

## 指定高度保持

只有四个关节点动方向都确认后，输入：

```text
confirm_dirs
height 100
```

`height 100` 表示以零点姿态附近的 100 mm 腿高为目标，程序会慢慢斜坡靠近，输出限制为很小的电压。安全范围暂时限制为 80 到 120 mm。

推荐使用监控脚本，它会先检查四个关节都是 `tested=yes`，再提示你确认方向，然后执行 `confirm_dirs` 和 `height 100`，并周期打印 CAN 和关节状态。结束或 Ctrl-C 后会自动执行 `holdoff`、`stop`、`disarm`：

```sh
cd /Users/ylris/轮腿/ParallelLegRobot
python3 tools/height_hold_monitor.py --port /dev/cu.usbmodem1301 --height 100 --duration 8
```

脚本会自动把完整输出保存到 `logs/height_hold_时间.txt`。这份日志就是判断“没有 CAN 掉线、电流异常、撞限位或明显抖动”的主要软件证据。

如果脚本提示不是四个 `tested=yes`，先回到单关节点动步骤。

两份日志都有后，可以用分析脚本做软件证据检查：

```sh
python3 tools/analyze_bringup_logs.py \
  --leg-log logs/leg_test_时间.txt \
  --height-log logs/height_hold_时间.txt
```

脚本通过只说明软件日志里没有看到 CAN 掉线、发送失败、电机离线等问题；电流是否异常、是否撞限位、是否明显抖动，仍然以现场观察为准。

停止：

```text
holdoff
stop
disarm
```

## 当前阶段验收标准

- 上电能稳定读到 ID1/2/5/6。
- 默认命令为 0 mV，不主动运动。
- `arm` 后可以安全点动单个关节。
- 确认方向后，两条腿能在架空状态下缓慢移动到指定高度并保持。
- 不出现 CAN 掉线、电流异常、撞限位或明显抖动。

完成以上内容，说明腿部控制链路已经基本打通；真正站立和平衡需要等轮电机、IMU、轮速和整车姿态闭环加入后再做。

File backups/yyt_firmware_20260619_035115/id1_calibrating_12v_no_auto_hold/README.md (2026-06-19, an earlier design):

# ID1 calibrating 12V no-auto-hold firmware

Purpose: diagnostic ID1 build after ID1 showed almost no positive motion with the unified skip-boot-sweep firmware.

Build flags:

- `DRIVE_ID=1`
- `DRIVE_AUTO_ZERO_HOLD=0`
- `YYT_UART_DEBUG=0`
- `MOTOR_SKIP_BOOT_SWEEP=0`
- `FOC_MODULATION_LIMIT=1.0f`

Expected behavior:

- Does not run drive-side power-on zero hold.
- Restores the startup motor sweep/electrical alignment before CAN control.
- Keeps CAN voltage command capability up to the 12 V limit used by the main controller.

Binary:

- `turing_CBU6_id1_calibrating_12v_no_auto_hold.bin`
- SHA-256: `18a352b9bff4a08cbc51402ed42d538a321d1821e62fe8a9395245694d5b9db0`

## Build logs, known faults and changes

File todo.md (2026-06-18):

# 轮腿机器人系统逐步调试指南 (System Debugging & Commissioning Checklist)

为了确保软硬件安全，避免因转向错误、大电压飞车、传感器异常导致机械结构损坏或驱动器烧毁，调试过程必须遵循**“先逻辑后动力、自底向上、软硬件解耦”**的原则。

---

## 阶段一：总线与通信调试 (Low-Level Communications Check)
*此阶段不加高压动力电（仅通逻辑电，如 5V/USB 供电），使机器人悬空离地。*

### [ ] Step 1.1: I2C 总线物理连接与电平诊断
- **调试对象**：ESP32-C3 I2C 物理引脚（`GPIO3=SCL`, `GPIO4=SDA`）与外部从设备之间的物理电气连接。
- **涉及代码/文件**：
  - [LegConfig.h](file:///home/waya/Projects/Embedded/ParallelLegRobot/include/LegConfig.h) (I2C 引脚定义 `I2C_SDA_PIN`, `I2C_SCL_PIN`)
  - [i2c_line_diagnostic.cpp](file:///home/waya/Projects/Embedded/ParallelLegRobot/src/i2c_line_diagnostic.cpp)
- **排查要点**：
  - [ ] 用万用表量取 `SDA/SCL` 对地阻抗，确认没有发生物理短路。
  - [ ] 烧录 `i2c-line-diagnostic` 固件，开启串口监视器，验证空闲状态下 `SDA=1`, `SCL=1`。若为 `0` 说明总线被拉低或短路。
  - [ ] 确认总线上存在物理上拉电阻（4.7kΩ 或 10kΩ 连至 3.3V）。

### [ ] Step 1.2: I2C 从设备在线扫描 (I2C Scanner)
- **调试对象**：MPU6050 IMU, 双侧磁编码器 (AS5600), STM32F103 协处理器。
- **涉及代码/文件**：
  - [main.cpp](file:///home/waya/Projects/Embedded/ParallelLegRobot/src/main.cpp) (函数 `scanI2cBus()`)
- **排查要点**：
  - [ ] 确保机器人整机上电（使外部传感器和 STM32F103 获得工作电压）。
  - [ ] 串口终端输入 `i2cscan` 指令。
  - [ ] 验证输出结果中正确检测到以下四个地址：
    - `0x12`：STM32F103 轮协处理器。
    - `0x36`：左轮磁编码器。
    - `0x38`：右轮磁编码器。
    - `0x68`：MPU6050 IMU 陀螺仪。
  - **安全提醒**：如果某个地址缺失，切勿继续后期的动力测试。

### [ ] Step 1.3: CAN 总线与关节驱动器通信
- **调试对象**：ESP32-C3 TWAI 控制器、TJA1050T 收发器、4 个腿关节电机驱动板（STM32G431）。
- **涉及代码/文件**：
  - [main.cpp](file:///home/waya/Projects/Embedded/ParallelLegRobot/src/main.cpp) (函数 `setupCan()`, `printCanStatus()`)
- **排查要点**：
  - [ ] 检查 CANH/CANL 差分线上是否有 120Ω 终端电阻（总线两端各一个）。
  - [ ] 串口输入 `can` 指令，确认 CAN 控制器状态为 `RUNNING`。
  - [ ] 串口输入 `status` 指令，验证 4 个关节电机状态均为 `yes` (Online)：
    - `ID1` (左上), `ID2` (左下), `ID5` (右上), `ID6` (右下)。

---

## 阶段二：传感器与状态反馈校验 (Sensor & Feedback Verification)
*确保控制算法获取 of 输入信号是物理正确的。*

### [ ] Step 2.1: 机身 IMU 姿态解算校验
- **调试对象**：MPU6050 陀螺仪与加速度计。
- **涉及代码/文件**：
  - [ImuManager.cpp](file:///home/waya/Projects/Embedded/ParallelLegRobot/src/ImuManager.cpp)
  - [main.cpp](file:///home/waya/Projects/Embedded/ParallelLegRobot/src/main.cpp) (指令 `imu`, `imustream on/off`)
- **排查要点**：
  - [ ] 机器人保持水平静止，输入 `imu`，检查初始 Pitch 角是否接近 `0.0`。
  - [ ] 输入 `imustream on`。手动让机器人向前倾斜，观察输出 Pitch 角变化是否为正，向后倾斜时是否为负。
  - [ ] 观察在剧烈摇晃后重新静止，Pitch 角能否迅速收敛至正确数值，有无积分漂移。

### [ ] Step 2.2: 车轮磁编码器旋向与范围校验
- **调试对象**：左轮 (`0x36`) 与右轮 (`0x38`) 的 AS5600 磁编码器。
- **涉及代码/文件**：
  - [main.cpp](file:///home/waya/Projects/Embedded/ParallelLegRobot/src/main.cpp) (函数 `readAS5600Encoder()`, 指令 `wheel`, `wheelstream on`)
- **排查要点**：
  - [ ] 输入 `wheelstream on`。
  - [ ] 手动旋转左轮和右轮整整一圈，检查 `raw_l` 和 `raw_r` 能否从 `0 ~ 4095` 满量程变化，且无断点跳变。
  - [ ] 验证旋向：
    - 车轮向前滚时，读数应呈递增变化；向后滚时呈递减变化。
    - 若数值方向相反，需在代码中取反，或调整物理极性。

---

## 阶段三：轮部 SimpleFOC 闭环对准与开环运行 (SimpleFOC Alignment & Drive)
*调校 STM32F103 的三相无刷驱动逻辑与 FOC 零点。车轮悬空！*

### [ ] Step 3.1: FOC 零电角度对齐 (FOC Motor Alignment)
- **调试对象**：STM32F103 协处理器、2 块 SimpleFOC 无刷驱动板、无刷轮电机。
- **涉及代码/文件**：
  - [f103_wheel_pwm.cpp](file:///home/waya/Projects/Embedded/ParallelLegRobot/src/f103_wheel_pwm.cpp) (函数 `setup()`, `motor_left.linkSensor(&sensor_left)`, `motor_left.init()`, `motor_left.initFOC()`)
- **排查要点**：
  - [ ] 车轮必须完全悬空，无外力干扰。
  - [ ] 主控 ESP32-C3 运行并保持发送 I2C 角度数据（`wheel_coprocessor_online` 显示 `online`）。
  - [ ] 给 STM32F103 上电，观察电机是否轻轻扭动（正反转）。
  - [ ] 检查 F103 上的 `PC13` 状态指示灯：对相校准通过后，该 LED 将从闪烁/常暗变为**常亮/变暗**。
  - **安全提醒**：如果对相失败，电机会剧烈震动、发热且无法转动。必须检查 F103 中配置的 `MOTOR_POLE_PAIRS`（电机极对数，当前为 11）是否与物理电机一致。

### [ ] Step 3.2: 轮子开环电压指令测试 (Open-Loop Voltage Drive)
- **调试对象**：3-PWM 无刷驱动器输出、轮子转向。
- **涉及代码/文件**：
  - [main.cpp](file:///home/waya/Projects/Embedded/ParallelLegRobot/src/main.cpp) (指令 `wheelarm`, `wheelpwm <left_pwm> <right_pwm>`, `wheeldisarm`)
- **排查要点**：
  - [ ] 输入 `wheelarm` 使能轮子控制器输出。
  - [ ] 输入微小电压：`wheelpwm 100 100`（占空比约 10%）。
  - [ ] 检查车轮是否平稳低速向前旋转。
  - [ ] 输入反向电压：`wheelpwm -100 -100`，确认车轮向后旋转。
  - [ ] 输入 `wheeldisarm` 确认车轮立刻停转且完全失去阻尼（变为自由状态）。

---

## 阶段四：腿部关节电机单腿闭环与高度保持 (Leg Zero Hold & Height Control)
*调校并联五杆腿部的运动学与零位保持。*

### [ ] Step 4.1: 腿电机单关节零点与极性测试
- **调试对象**：4 个 leg 关节电机。
- **涉及代码/文件**：
  - [main.cpp](file:///home/waya/Projects/Embedded/ParallelLegRobot/src/main.cpp) (指令 `dirs`, `confirm_dirs`, `zero <id>`)
- **排查要点**：
  - [ ] 用手托住机械腿，输入 `dirs`，手动微动各关节，配合串口输出验证其极性符号是否物理正确。
  - [ ] 极性验证无误后，输入 `confirm_dirs`。
  - [ ] 输入 `arm`，然后输入 `zero 1`，锁死 1 号电机。用手转动 1 号关节主动臂，感受是否有极强的阻力（PD 刚度）。
  - [ ] 依次测试 `zero 2`, `zero 5`, `zero 6`。
  - **安全提醒**：一旦发现电机啸叫、剧烈震动或向单方向飞车，必须立刻输入 `stop` 或 `disarm` 切断输出！

### [ ] Step 4.2: 双腿协同高度保持 (Zero Hold / Height Control)
- **调试对象**：并联五杆腿部高度 PD 控制器、足端反力。
- **涉及代码/文件**：
  - [LegKinematics.cpp](file:///home/waya/Projects/Embedded/ParallelLegRobot/src/LegKinematics.cpp)
  - [main.cpp](file:///home/waya/Projects/Embedded/ParallelLegRobot/src/main.cpp) (指令 `zero`, `holdoff`)
- **排查要点**：
  - [ ] 机器人双腿着地，双手扶住机身以防倾倒，输入 `zero`。
  - [ ] 观察机器人是否能够自主站立（高度支撑在默认 100mm 附近）。
  - [ ] 手动轻轻向下按压机身，检查机械腿是否表现出类似于物理弹簧的弹性支撑和阻尼感。

---

## 阶段五：车体动静态自平衡联调 (Self-Balancing Coordination)
*将 Pitch 反馈引入车轮控制环路，实现自平衡站立。*

### [ ] Step 5.1: 直立环（角度 PD 控制）调试
- **调试对象**：自平衡直立环控制算法、双轮差速响应。
- **涉及代码/文件**：
  - [main.cpp](file:///home/waya/Projects/Embedded/ParallelLegRobot/src/main.cpp) (直立环 PID 计算代码段)
- **排查要点**：
  - [ ] 先将速度环参数置零，仅保留较小的直立环参数（`Kp_pitch`, `Kd_pitch`）。
  - [ ] 双轮着地，人手扶住机身让其小幅度前后倾斜。
  - [ ] 校验响应：
    - 车身向前倾斜时，双轮必须立刻向前加速运动；车身后仰时，双轮必须立刻向后退。
    - 若轮子运动方向相反（导致加速摔倒），需要对直立环控制输出或轮子 PWM 符号进行取反。
  - [ ] 逐步加大 `Kp_pitch` 直至手松开后车身能产生短暂 of 直立恢复力，且不产生剧烈的高频震荡。

### [ ] Step 5.2: 速度环（位置/速度 PI 控制）融入
- **调试对象**：速度反馈低通滤波器、平衡收敛点。
- **涉及代码/文件**：
  - [main.cpp](file:///home/waya/Projects/Embedded/ParallelLegRobot/src/main.cpp) (速度环 PID 计算代码段)
- **排查要点**：
  - [ ] 逐步引入速度环 `Kp_speed` 和 `Ki_speed`，用以消除车体在一个方向上的持续漂移。
  - [ ] 测试用手轻推车身，车身倾斜避让后是否能够迅速回到原定站立点。
  - [ ] 观察在粗糙或地毯等不同地面上，机器人的自平衡静态稳定性。

---

## 阶段六：高级轮腿融合控制 (Advanced Leg-Wheel Integration)
*实现动态高度变化、差速转向与弹跳。*

### [ ] Step 6.1: 变高度站立与差速转向
- **调试对象**：腿部几何解算（IK/FK）动态更新，轮部差速偏置。
- **排查要点**：
  - [ ] 在自平衡站立状态下，发送高度修改指令（例如从 100mm 降到 80mm），观察双腿是否能平稳下蹲而不影响自平衡。
  - [ ] 差速发送转向指令，测试机器人能否进行原地自转（Spin）与前行弯道转向（Yaw 轴偏航控制）。

### [ ] Step 6.2: 动态推地与跳跃
- **调试对象**：关节电机前馈力矩（Feedforward Torque）与虚拟阻抗力矩控制。
- **排查要点**：
  - [ ] 调优高度控制器，输出瞬间向下的爆发力以离地。
  - [ ] 离地瞬时快速收回机械腿（改变工作高度目标值），避免触地硬撞。
  - [ ] 落地时，切换为大阻尼、小刚度的 PD 虚拟阻抗参数，完成软着陆吸能缓冲。

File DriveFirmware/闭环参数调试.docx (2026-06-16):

固定一相为U，其他两相分配为V和W，线序的问题会影响正反转，故需要进行sensor_direction标定

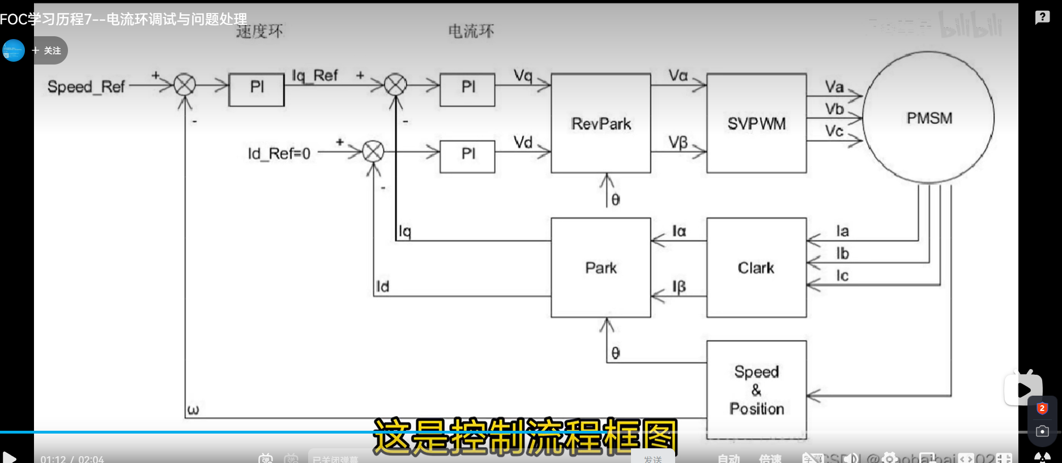
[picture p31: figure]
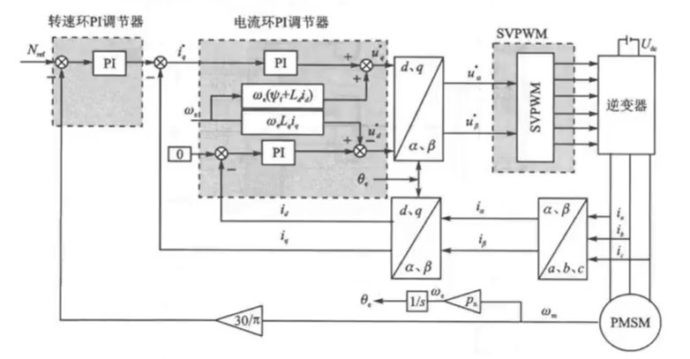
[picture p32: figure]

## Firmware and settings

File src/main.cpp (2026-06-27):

#include <Arduino.h>
#include <Wire.h>
#include "driver/twai.h"
#include "LegConfig.h"
#include "LegKinematics.h"
#include "ImuManager.h"

#ifndef YYT_CAN_RX_PIN
#define YYT_CAN_RX_PIN 7
#endif

#ifndef YYT_CAN_TX_PIN
#define YYT_CAN_TX_PIN 6
#endif

#ifndef YYT_SAFE_MV_LIMIT
#define YYT_SAFE_MV_LIMIT 12000
#endif

#ifndef YYT_HOLD_MV_LIMIT
#define YYT_HOLD_MV_LIMIT 12000
#endif

#ifndef YYT_MIN_TEST_MV
#define YYT_MIN_TEST_MV 0
#endif

#ifndef YYT_DISABLE_I2C
#define YYT_DISABLE_I2C 0
#endif

#ifndef YYT_ALLOW_UNTESTED_DIRS
#define YYT_ALLOW_UNTESTED_DIRS 0
#endif

static constexpr int kLedPin = 10;
static constexpr float kPi = 3.14159265358979323846f;
static constexpr float kTwoPi = 2.0f * kPi;
static constexpr uint32_t kCommandPeriodMs = 20;
static constexpr uint32_t kSummaryPeriodMs = 1000;
static constexpr uint32_t kImuStreamPeriodMs = 50;
static constexpr uint32_t kOnlineTimeoutMs = 500;
static constexpr uint32_t kWheelStatePeriodMs = 20; // 50 Hz update for wheel I2C/FOC angles
static constexpr uint32_t kBalancePeriodMs = 20;
static constexpr int16_t kWheelPwmLimit = 1000;
static constexpr int16_t kWheelVelocityLimitMradPerSec = 12000;
static constexpr float kBalanceDefaultKpMradPerSecPerDeg = 220.0f;
static constexpr float kBalanceDefaultKdMradPerSecPerDegS = 18.0f;
static constexpr float kBalanceAbortPitchDeg = 35.0f;
static constexpr float kStandbyXmm = 0.0f;
static constexpr float kStandbyYmm = -100.0f;
static constexpr float kHeightMinMm = 25.0f;
static constexpr float kHeightMaxMm = 120.0f;
static constexpr float kTargetRampRadPerSec = 0.22f;
static constexpr float kJointSoftLimitRad = 3.40f;
static constexpr float kHoldKpDefaultMvPerRad = 10000.0f;
static constexpr float kHoldKpId2MvPerRad = 19000.0f;
static constexpr float kHoldKpId5MvPerRad = 18000.0f;
static constexpr float kHoldKpId6MvPerRad = 19000.0f;
static constexpr float kHoldKdMvPerRadSec = 700.0f;
static constexpr float kHoldStaticBoostThresholdRad = 0.020f;
static constexpr float kHoldStaticBoostFullRad = 0.120f;
static constexpr float kHoldStaticBoostId2Mv = 0.0f;
static constexpr float kHoldStaticBoostId5Mv = 0.0f;
static constexpr float kHoldStaticBoostId6Mv = 0.0f;
static constexpr float kHoldFeedforwardId2Mv = -900.0f;
static constexpr float kHoldFeedforwardId5Mv = +1200.0f;
static constexpr float kHoldFeedforwardId6Mv = -700.0f;
static constexpr float kHoldFullPushThresholdRad = 0.35f;
static constexpr float kId5LiftFullPushThresholdRad = 0.12f;
static constexpr float kId5UpperMirrorOffsetRad = 0.90f;
static constexpr float kId6LowerMirrorOffsetRad = 0.90f;
static constexpr float kId6LowerMirrorGain = 0.35f;
static constexpr float kIkRetractionGain = 1.20f;
static constexpr float kFixedPoseTargetId1Rad = -0.063f;
static constexpr float kFixedPoseTargetId2Rad = +0.423f;
static constexpr float kFixedPoseTargetId5Rad = -0.076f;
static constexpr float kFixedPoseTargetId6Rad = +0.209f;
static constexpr float kStandRelativeStepRad = 0.10f;
static constexpr float kFeedbackJumpRejectRad = 0.80f;
static constexpr int16_t kZeroHoldMvLimit = YYT_HOLD_MV_LIMIT;
static constexpr int16_t kHoldHereMvLimit = 6000;
static constexpr uint32_t kBootFixedPoseDelayMs = 2500;
static constexpr int16_t kOpenLoopSpinMv = 4321;
static constexpr int16_t kDriveZeroHoldMv = 2345;
static constexpr uint32_t kCanRecoveryCooldownMs = 500;
static constexpr uint32_t kCanTxPauseMs = 500;
static constexpr uint32_t kCanTxQueueHighWater = 8;
static constexpr uint32_t kCanTxErrorRecoveryThreshold = 96;

struct MotorConfig {
  int id;
  const char *name;
  float zero_rad;
  int sign;
  int drive_sign;
};

struct MotorState {
  int32_t raw_angle_mrad = 0;
  int16_t speed_rpm_x10 = 0;
  uint16_t adc4_raw = 0;
  uint32_t last_ms = 0;
  bool feedback_seen = false;
  uint32_t rejected_jumps = 0;
  float angle_rad = 0.0f;
  float joint_rad = 0.0f;
  float speed_rad_s = 0.0f;
};

static constexpr MotorConfig kMotors[] = {
    {1, "left_front_upper", 4.860f, -1, -1},
    {2, "left_rear_lower", 5.553f, -1, -1},
    {5, "right_front_upper", 0.161f, -1, -1},
    {6, "right_rear_lower", 1.991f, +1, +1},
};

static MotorState motor_state[9];
static int16_t command_mv[9] = {};
static int motor_sign[9] = {};
static bool direction_tested[9] = {};
static bool armed = false;
static bool direction_confirmed = false;
static bool height_hold_enabled = false;
static bool hold_requires_direction_confirmed = true;
static bool hold_motor_enabled[9] = {};
static bool boot_fixed_pose_pending = false;
static float desired_target[9] = {};
static float ramped_target[9] = {};
static uint32_t last_command_ms = 0;
static uint32_t last_summary_ms = 0;
static uint32_t last_imu_stream_ms = 0;
static uint32_t last_wheel_stream_ms = 0;
static uint32_t last_wheel_state_ms = 0;
static uint32_t last_balance_ms = 0;
static uint32_t last_hold_update_ms = 0;
static uint32_t tx_fail_count = 0;
static uint32_t can_recovery_count = 0;
static uint32_t last_can_recovery_ms = 0;
static uint32_t last_boot_fixed_pose_attempt_ms = 0;
static uint32_t can_tx_pause_until_ms = 0;
static uint8_t last_left_tx_data[8] = {};
static uint8_t last_right_tx_data[8] = {};
static uint32_t last_left_tx_ms = 0;
static uint32_t last_right_tx_ms = 0;
static uint32_t height_hold_start_tx_fail = 0;
static uint32_t height_hold_start_bus_error = 0;
static int16_t active_hold_mv_limit = YYT_HOLD_MV_LIMIT;
static String serial_line;
static LegKinematics kinematics;
static ImuManager imu;
static bool imu_stream_enabled = false;
static bool wheel_armed = false;
static bool left_wheel_encoder_online = false;
static bool right_wheel_encoder_online = false;
static bool wheel_coprocessor_online = false;
static bool wheel_stream_enabled = false;
static uint16_t left_wheel_encoder_raw = 0;
static uint16_t right_wheel_encoder_raw = 0;
static float left_wheel_angle_rad = 0.0f;
static float right_wheel_angle_rad = 0.0f;
static int16_t wheel_left_pwm = 0;
static int16_t wheel_right_pwm = 0;
static int16_t wheel_left_velocity_mrad_s = 0;
static int16_t wheel_right_velocity_mrad_s = 0;
static bool wheel_velocity_mode = false;
static bool drive_enabled = false;
static int16_t drive_forward_mrad_s = 0;
static int16_t drive_turn_mrad_s = 0;
static int drive_left_sign = 1;
static int drive_right_sign = 1;
static bool balance_enabled = false;
static float balance_pitch_target_deg = 0.0f;
static float balance_kp_mrad_per_sec_per_deg = kBalanceDefaultKpMradPerSecPerDeg;
static float balance_kd_mrad_per_sec_per_deg_s = kBalanceDefaultKdMradPerSecPerDegS;
static int balance_left_sign = 1;
static int balance_right_sign = 1;

static float normalizeRad(float rad) {
  while (rad > kPi) rad -= kTwoPi;
  while (rad < -kPi) rad += kTwoPi;
  return rad;
}

static int16_t clampMv(long mv, int limit = YYT_SAFE_MV_LIMIT) {
  if (mv > limit) return static_cast<int16_t>(limit);
  if (mv < -limit) return static_cast<int16_t>(-limit);
  return static_cast<int16_t>(mv);
}

static int16_t clampTestMv(long mv) {
  const int16_t limited = clampMv(mv);
  if (limited == 0) return 0;
  if (abs(limited) == kDriveZeroHoldMv) return limited;
  if (abs(limited) == kOpenLoopSpinMv) return limited;
  if (abs(limited) < YYT_MIN_TEST_MV) {
    return limited > 0 ? YYT_MIN_TEST_MV : -YYT_MIN_TEST_MV;
  }
  return limited;
}

static int16_t clampWheelVelocityMradS(long velocity_mrad_s) {
  if (velocity_mrad_s > kWheelVelocityLimitMradPerSec) return kWheelVelocityLimitMradPerSec;
  if (velocity_mrad_s < -kWheelVelocityLimitMradPerSec) return -kWheelVelocityLimitMradPerSec;
  return static_cast<int16_t>(velocity_mrad_s);
}

static const MotorConfig *findMotor(int id) {
  for (const auto &motor : kMotors) {
    if (motor.id == id) return &motor;
  }
  return nullptr;
}

static bool isMotorOnline(int id) {
  return motor_state[id].last_ms != 0 && millis() - motor_state[id].last_ms < kOnlineTimeoutMs;
}

static bool allLegMotorsOnline() {
  for (const auto &motor : kMotors) {
    if (!isMotorOnline(motor.id)) return false;
  }
  return true;
}

static bool anyLegMotorOnline() {
  for (const auto &motor : kMotors) {
    if (isMotorOnline(motor.id)) return true;
  }
  return false;
}

static bool allDirectionsTested() {
  for (const auto &motor : kMotors) {
    if (!direction_tested[motor.id]) return false;
  }
  return true;
}

static void clearCommands() {
  for (int i = 0; i < 9; ++i) command_mv[i] = 0;
}

static void clearHoldMotorEnabled() {
  for (int i = 0; i < 9; ++i) hold_motor_enabled[i] = false;
}

static bool hasActiveMotorCommand() {
  for (const auto &motor : kMotors) {
    if (command_mv[motor.id] != 0) return true;
  }
  return false;
}

static void stopHeightHold(const char *reason) {
  height_hold_enabled = false;
  hold_requires_direction_confirmed = true;
  clearHoldMotorEnabled();
  clearCommands();
  Serial.printf("height hold stopped: %s\n", reason);
}

static const char *twaiStateName(twai_state_t state) {
  switch (state) {
    case TWAI_STATE_STOPPED:
      return "stopped";
    case TWAI_STATE_RUNNING:
      return "running";
    case TWAI_STATE_BUS_OFF:
      return "bus_off";
    case TWAI_STATE_RECOVERING:
      return "recovering";
    default:
      return "unknown";
  }
}

static void putInt16LE(uint8_t *data, int slot, int16_t value) {
  const int offset = slot * 2;
  data[offset] = static_cast<uint8_t>(value & 0xff);
  data[offset + 1] = static_cast<uint8_t>((value >> 8) & 0xff);
}

static int32_t getInt32LE(const uint8_t *data) {
  return static_cast<int32_t>(static_cast<uint32_t>(data[0]) |
                              (static_cast<uint32_t>(data[1]) << 8) |
                              (static_cast<uint32_t>(data[2]) << 16) |
                              (static_cast<uint32_t>(data[3]) << 24));
}

static int16_t getInt16LE(const uint8_t *data) {
  return static_cast<int16_t>(static_cast<uint16_t>(data[0]) |
                              (static_cast<uint16_t>(data[1]) << 8));
}

static bool i2cDevicePresent(uint8_t addr) {
  Wire.beginTransmission(addr);
  return Wire.endTransmission() == 0;
}

static void scanI2cBus() {
  Serial.println("Scanning I2C bus...");
  int found = 0;
  for (uint8_t addr = 1; addr < 0x7f; ++addr) {
    if (i2cDevicePresent(addr)) {
      Serial.printf("  found 0x%02X", addr);
      if (addr == MPU6050_I2C_ADDR) Serial.print(" MPU6050");
      if (addr == WHEEL_PWM_COPROCESSOR_I2C_ADDR) Serial.print(" STM32F103-wheel-pwm");
      if (addr == LEFT_WHEEL_ENCODER_I2C_ADDR) Serial.print(" left-wheel-encoder");
      if (addr == RIGHT_WHEEL_ENCODER_I2C_ADDR) Serial.print(" right-wheel-encoder");
      Serial.println();
      found++;
    }
  }
  Serial.printf("I2C scan done, %d device(s)\n", found);
}

static bool readAS5600Encoder(uint8_t addr, uint16_t &raw, float &angle) {
  Wire.beginTransmission(addr);
  Wire.write(0x0C);
  if (Wire.endTransmission(false) != 0) {
    return false;
  }

  const uint8_t got = Wire.requestFrom(addr, static_cast<uint8_t>(2));
  if (got != 2 || Wire.available() < 2) {
    return false;
  }

  const uint8_t high = Wire.read();
  const uint8_t low = Wire.read();
  raw = static_cast<uint16_t>(((high & 0x0f) << 8) | low);
  angle = static_cast<float>(raw) * kTwoPi / 4096.0f;
  return true;
}

static bool sendWheelCommandToCoprocessor(uint8_t command, int16_t left_value, int16_t right_value) {
  if (YYT_DISABLE_I2C) {
    wheel_coprocessor_online = false;
    return false;
  }

  Wire.beginTransmission(WHEEL_PWM_COPROCESSOR_I2C_ADDR);
  Wire.write(command);
  Wire.write(static_cast<uint8_t>(left_value & 0xff));
  Wire.write(static_cast<uint8_t>((left_value >> 8) & 0xff));
  Wire.write(static_cast<uint8_t>(right_value & 0xff));
  Wire.write(static_cast<uint8_t>((right_value >> 8) & 0xff));
  // Send Left and Right raw encoder angles to STM32F103 for FOC commutation
  Wire.write(static_cast<uint8_t>(left_wheel_encoder_raw & 0xff));
  Wire.write(static_cast<uint8_t>((left_wheel_encoder_raw >> 8) & 0xff));
  Wire.write(static_cast<uint8_t>(right_wheel_encoder_raw & 0xff));
  Wire.write(static_cast<uint8_t>((right_wheel_encoder_raw >> 8) & 0xff));
  const bool ok = Wire.endTransmission() == 0;

  wheel_coprocessor_online = ok;
  return ok;
}

static bool sendWheelPwmToCoprocessor(int16_t left_pwm, int16_t right_pwm) {
  left_pwm = constrain(left_pwm, -kWheelPwmLimit, kWheelPwmLimit);
  right_pwm = constrain(right_pwm, -kWheelPwmLimit, kWheelPwmLimit);

  const bool ok = sendWheelCommandToCoprocessor(0x10, left_pwm, right_pwm);
  if (ok) {
    wheel_left_pwm = left_pwm;
    wheel_right_pwm = right_pwm;
    wheel_left_velocity_mrad_s = 0;
    wheel_right_velocity_mrad_s = 0;
    wheel_velocity_mode = false;
  }
  return ok;
}

static bool sendWheelVelocityToCoprocessor(int16_t left_mrad_s, int16_t right_mrad_s) {
  left_mrad_s = constrain(left_mrad_s, -kWheelVelocityLimitMradPerSec, kWheelVelocityLimitMradPerSec);
  right_mrad_s = constrain(right_mrad_s, -kWheelVelocityLimitMradPerSec, kWheelVelocityLimitMradPerSec);

  const bool ok = sendWheelCommandToCoprocessor(0x11, left_mrad_s, right_mrad_s);
  if (ok) {
    wheel_left_velocity_mrad_s = left_mrad_s;
    wheel_right_velocity_mrad_s = right_mrad_s;
    wheel_left_pwm = 0;
    wheel_right_pwm = 0;
    wheel_velocity_mode = true;
  }
  return ok;
}

static void stopWheelCommand() {
  wheel_left_pwm = 0;
  wheel_right_pwm = 0;
  wheel_left_velocity_mrad_s = 0;
  wheel_right_velocity_mrad_s = 0;
  wheel_velocity_mode = true;
  (void)sendWheelVelocityToCoprocessor(0, 0);
}

static void updateWheelDevices() {
  left_wheel_encoder_online = i2cDevicePresent(LEFT_WHEEL_ENCODER_I2C_ADDR) &&
                              readAS5600Encoder(LEFT_WHEEL_ENCODER_I2C_ADDR, left_wheel_encoder_raw, left_wheel_angle_rad);
  right_wheel_encoder_online = i2cDevicePresent(RIGHT_WHEEL_ENCODER_I2C_ADDR) &&
                               readAS5600Encoder(RIGHT_WHEEL_ENCODER_I2C_ADDR, right_wheel_encoder_raw, right_wheel_angle_rad);
  wheel_coprocessor_online = i2cDevicePresent(WHEEL_PWM_COPROCESSOR_I2C_ADDR);

  if (!wheel_armed && (wheel_left_pwm != 0 || wheel_right_pwm != 0 ||
                       wheel_left_velocity_mrad_s != 0 || wheel_right_velocity_mrad_s != 0)) {
    stopWheelCommand();
  }
}

static void printWheelStatus() {
  Serial.printf("wheel: armed=%s mode=%s balance=%s drive=%s f103=%s left_enc=%s(0x%02X) raw_l=%u angle_l=%.4f rad | right_enc=%s(0x%02X) raw_r=%u angle_r=%.4f rad | pwm_l=%d pwm_r=%d vel_l=%d vel_r=%d mrad/s drive_fwd=%d drive_turn=%d drive_signs=[%+d,%+d] pitch_target=%.2f kp=%.1f kd=%.1f balance_signs=[%+d,%+d]\n",
                wheel_armed ? "yes" : "no",
                wheel_velocity_mode ? "velocity" : "pwm",
                balance_enabled ? "on" : "off",
                drive_enabled ? "on" : "off",
                wheel_coprocessor_online ? "online" : "offline",
                left_wheel_encoder_online ? "online" : "offline",
                LEFT_WHEEL_ENCODER_I2C_ADDR,
                left_wheel_encoder_raw,
                left_wheel_angle_rad,
                right_wheel_encoder_online ? "online" : "offline",
                RIGHT_WHEEL_ENCODER_I2C_ADDR,
                right_wheel_encoder_raw,
                right_wheel_angle_rad,
                wheel_left_pwm,
                wheel_right_pwm,
                wheel_left_velocity_mrad_s,
                wheel_right_velocity_mrad_s,
                drive_forward_mrad_s,
                drive_turn_mrad_s,
                drive_left_sign,
                drive_right_sign,
                balance_pitch_target_deg,
                balance_kp_mrad_per_sec_per_deg,
                balance_kd_mrad_per_sec_per_deg_s,
                balance_left_sign,
                balance_right_sign);
}

static void stopDrive(const char *reason) {
  if (drive_enabled) {
    Serial.printf("drive stopped: %s\n", reason);
  }
  drive_enabled = false;
  drive_forward_mrad_s = 0;
  drive_turn_mrad_s = 0;
  if (!balance_enabled) {
    (void)sendWheelVelocityToCoprocessor(0, 0);
  }
}

static void stopBalance(const char *reason) {
  if (balance_enabled) {
    Serial.printf("balance stopped: %s\n", reason);
  }
  balance_enabled = false;
  if (!drive_enabled) {
    (void)sendWheelVelocityToCoprocessor(0, 0);
  }
}

static void serviceWheelVelocityControl() {
  if (!balance_enabled && !drive_enabled) return;

  const uint32_t now = millis();
  if (now - last_balance_ms < kBalancePeriodMs) return;
  last_balance_ms = now;

  if (!wheel_armed) {
    stopBalance("wheel disarmed");
    stopDrive("wheel disarmed");
    stopWheelCommand();
    return;
  }

  int16_t balance_velocity_mrad_s = 0;
  if (balance_enabled) {
    if (!imu.isConnected()) {
      stopBalance("IMU offline");
      return;
    }

    const float pitch_deg = imu.getPitch();
    const float pitch_rate_deg_s = imu.getPitchRateDegS();
    if (fabsf(pitch_deg - balance_pitch_target_deg) > kBalanceAbortPitchDeg) {
      stopBalance("pitch outside abort limit");
      stopDrive("pitch outside abort limit");
      stopWheelCommand();
      return;
    }

    const float pitch_err_deg = pitch_deg - balance_pitch_target_deg;
    const float base_velocity_mrad_s =
        balance_kp_mrad_per_sec_per_deg * pitch_err_deg +
        balance_kd_mrad_per_sec_per_deg_s * pitch_rate_deg_s;
    balance_velocity_mrad_s = clampWheelVelocityMradS(lroundf(base_velocity_mrad_s));
  }

  long left_velocity = 0;
  long right_velocity = 0;
  if (drive_enabled) {
    left_velocity += static_cast<long>(drive_left_sign) *
                     (static_cast<long>(drive_forward_mrad_s) - drive_turn_mrad_s);
    right_velocity += static_cast<long>(drive_right_sign) *
                      (static_cast<long>(drive_forward_mrad_s) + drive_turn_mrad_s);
  }
  if (balance_enabled) {
    left_velocity += static_cast<long>(balance_left_sign) * balance_velocity_mrad_s;
    right_velocity += static_cast<long>(balance_right_sign) * balance_velocity_mrad_s;
  }

  if (!sendWheelVelocityToCoprocessor(clampWheelVelocityMradS(left_velocity),
                                      clampWheelVelocityMradS(right_velocity))) {
    balance_enabled = false;
    drive_enabled = false;
    drive_forward_mrad_s = 0;
    drive_turn_mrad_s = 0;
    stopWheelCommand();
    Serial.println("wheel velocity control stopped: I2C send failed");
  }
}

static bool sendGroup(uint32_t can_id, int first_motor_id) {
  twai_message_t msg = {};
  msg.identifier = can_id;
  msg.data_length_code = 8;
  msg.flags = TWAI_MSG_FLAG_NONE;

  for (int slot = 0; slot < 4; ++slot) {
    const int id = first_motor_id + slot;
    const int16_t mv = armed ? command_mv[id] : 0;
    putInt16LE(msg.data, slot, mv);
  }

  const esp_err_t err = twai_transmit(&msg, pdMS_TO_TICKS(5));
  if (err != ESP_OK) {
    tx_fail_count++;
    return false;
  }
  const uint32_t now = millis();
  if (can_id == 0x100) {
    memcpy(last_left_tx_data, msg.data, sizeof(last_left_tx_data));
    last_left_tx_ms = now;
  } else if (can_id == 0x200) {
    memcpy(last_right_tx_data, msg.data, sizeof(last_right_tx_data));
    last_right_tx_ms = now;
  }
  return true;
}
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
void loop() {
  receiveFeedback();

  if (!YYT_DISABLE_I2C) {
    imu.update();
  }

  while (Serial.available() > 0) {
    const char c = static_cast<char>(Serial.read());
    if (c == '\n' || c == '\r') {
      handleCommand(serial_line);
      serial_line = "";
    } else if (serial_line.length() < 120) {
      serial_line += c;
    }
  }

  const uint32_t now = millis();
  if (now - last_command_ms >= kCommandPeriodMs) {
    last_command_ms = now;
    serviceCanRecovery();
    tryEnableBootFixedPoseHold();
    updateHeightHold();
    sendMotorCommands();
    // Breathing LED using sine wave. Faster when armed.
    float speed = armed ? 0.006f : 0.002f;
    float breathingVal = sin(now * speed);
    int brightness = (int)(127.5f * (1.0f + breathingVal));
    analogWrite(kLedPin, brightness);
  }

  if (!YYT_DISABLE_I2C && now - last_wheel_state_ms >= kWheelStatePeriodMs) {
    last_wheel_state_ms = now;
    updateWheelDevices();
  }
  if (!YYT_DISABLE_I2C) {
    serviceWheelVelocityControl();
  }

  if (!YYT_DISABLE_I2C && imu_stream_enabled && imu.isConnected() && now - last_imu_stream_ms >= kImuStreamPeriodMs) {
    last_imu_stream_ms = now;
    Serial.printf("imu:%.2f,%.2f,%.2f,0.0,0.0,0.0\n",
                  imu.getPitch(),
                  imu.getRoll(),
                  imu.getYaw());
  }

  if (wheel_stream_enabled && now - last_wheel_stream_ms >= kImuStreamPeriodMs) {
    last_wheel_stream_ms = now;
    Serial.printf("wheel:%.4f,%.4f,%d,%d,%d,%d,%s,%s,%s,%s\n",
                  left_wheel_angle_rad,
                  right_wheel_angle_rad,
                  wheel_left_pwm,
                  wheel_right_pwm,
                  wheel_left_velocity_mrad_s,
                  wheel_right_velocity_mrad_s,
                  balance_enabled ? "balance_on" : "balance_off",
                  wheel_coprocessor_online ? "f103_online" : "f103_offline",
                  left_wheel_encoder_online ? "L_online" : "L_offline",
                  right_wheel_encoder_online ? "R_online" : "R_offline");
  }

  if (now - last_summary_ms >= kSummaryPeriodMs) {
    last_summary_ms = now;
    Serial.printf("online: ID1=%s ID2=%s ID5=%s ID6=%s armed=%s hold=%s wheel_f103=%s wheel_enc_L=%s wheel_enc_R=%s\n",
                  isMotorOnline(1) ? "yes" : "no",
                  isMotorOnline(2) ? "yes" : "no",
                  isMotorOnline(5) ? "yes" : "no",
                  isMotorOnline(6) ? "yes" : "no",
                  armed ? "yes" : "no",
                  height_hold_enabled ? "on" : "off",
                  wheel_coprocessor_online ? "yes" : "no",
                  left_wheel_encoder_online ? "yes" : "no",
                  right_wheel_encoder_online ? "yes" : "no");
  }
}

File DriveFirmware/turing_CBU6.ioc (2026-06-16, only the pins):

Mcu.UserName=STM32G431CBUx
PA0.Signal=ADC1_IN1
PA1.Signal=ADC1_IN2
PA10.Signal=S_TIM1_CH3
PA11.Signal=GPIO_Output
PA13.Signal=SYS_JTMS-SWDIO
PA14.Signal=SYS_JTCK-SWCLK
PA2.Signal=ADC1_IN3
PA3.Signal=ADC1_IN4
PA4.Signal=GPIO_Output
PA5.Signal=SPI1_SCK
PA6.Signal=SPI1_MISO
PA7.Signal=SPI1_MOSI
PA8.Signal=S_TIM1_CH1
PA9.Signal=S_TIM1_CH2
PB12.Signal=GPIO_Output
PB13.Signal=TIM1_CH1N
PB14.Signal=TIM1_CH2N
PB15.Signal=TIM1_CH3N
PB6.Signal=USART1_TX
PB7.Signal=USART1_RX
PB8-BOOT0.Signal=FDCAN1_RX
PB9.Signal=FDCAN1_TX
PF0-OSC_IN.Signal=RCC_OSC_IN
PF1-OSC_OUT.Signal=RCC_OSC_OUT

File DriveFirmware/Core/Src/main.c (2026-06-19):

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
/* Includes ------------------------------------------------------------------*/
#include "main.h"
#include "adc.h"
#include "dma.h"
#include "fdcan.h"
#include "spi.h"
#include "tim.h"
#include "usart.h"
#include "gpio.h"

/* USER CODE BEGIN Includes */
#include "Data.h"
#include "FOC.h"
#include "mt6816.h"
#include "Motor.h"
#include "Lowpass.h"
#include "can_bridge.h"
#include "drive_uart_debug.h"
#include <string.h>
#include <stdio.h>
#include <stdarg.h>
#include <stdlib.h>
/* USER CODE END Includes */


/* USER CODE BEGIN PV */
static uint8_t dma_in_process=0;
static uint32_t overflow_count = 0;
static uint8_t buffer_receive[100];
static volatile uint8_t motor_calibration_requested=0;
/* USER CODE END PV */

#ifndef YYT_SAFE_START
#define YYT_SAFE_START 1
#endif

#ifndef YYT_DISABLE_OUTPUT
#define YYT_DISABLE_OUTPUT 0
#endif

#ifndef YYT_UART_DEBUG
#define YYT_UART_DEBUG 0
#endif

void SystemClock_Config(void);
/* USER CODE BEGIN PFP */
uint32_t Get_Timestamp_us(void)
{
    uint32_t timestamp = 0;
    uint32_t current_count;
	
    __disable_irq();
    current_count = __HAL_TIM_GET_COUNTER(&htim4);
    timestamp = (overflow_count * 0xFFFF + current_count); // 1MHz
    __enable_irq();

    return timestamp;
}

float parseData(const char* input)
{
		const char* equalSign_ptr = strchr(input, '=');
    if (equalSign_ptr == NULL)
    {
        return -1.0f;
    }
		const char* end = strchr(input, '!');
    if (end == NULL)
    {
        return -2.0f;
    }
		const char* data_ptr=equalSign_ptr+1;
		
		char command[16]; 
    char data[16]; 
    size_t command_length = equalSign_ptr - input;
		size_t data_length=end-data_ptr;
   
    strncpy(command, input, command_length);
		strncpy(data, data_ptr, data_length);
    command[command_length] = '\0'; 
		data[data_length] = '\0'; 
		float data_flt=1.0f;
    if(strcmp(command,"P1")==0)
		{
			PID_Pos.P= atof(data);
			
		}
		else if(strcmp(command,"I1")==0)
		{
			PID_Pos.I= atof(data);
		}
		else if(strcmp(command,"D1")==0)
		{
			PID_Pos.D= atof(data);
		}
		else if(strcmp(command,"P0")==0)
		{
			Pos_set= atof(data);
		}
		else if(strcmp(command,"V0")==0)
		{
			Velo_set= atof(data);
		}
		else if(strcmp(command,"P2")==0)
		{
			PID_Vel.P= atof(data);
		}
		else if(strcmp(command,"I2")==0)
		{
			PID_Vel.I= atof(data);
		}
		else if(strcmp(command,"D2")==0)
		{
			PID_Vel.D= atof(data);
		}
		else if(strcmp(command,"Q0")==0)
		{
			IQ_set= atof(data);
		}
		else if(strcmp(command,"D0")==0)
		{
			ID_set= atof(data);
		}
		
		else if(strcmp(command,"P3")==0)
		{
			PID_Cur_Q.P= atof(data);
		}
		else if(strcmp(command,"I3")==0)
		{
			PID_Cur_Q.I= atof(data);
		}
		else if(strcmp(command,"D3")==0)
		{
			PID_Cur_Q.D= atof(data);
		}
		else if(strcmp(command,"P4")==0)
		{
			PID_Cur_D.P= atof(data);
		}
		else if(strcmp(command,"I4")==0)
		{
			PID_Cur_D.I= atof(data);
		}
		else if(strcmp(command,"D4")==0)
		{
			PID_Cur_D.D= atof(data);
		}
		else if(strcmp(command,"P5")==0)
		{
			PID_Vel_Cur.P= atof(data);
		}
		else if(strcmp(command,"I5")==0)
		{
			PID_Vel_Cur.I= atof(data);
		}
		else if(strcmp(command,"D5")==0)
		{
			PID_Vel_Cur.D= atof(data);
		}
		else if(strcmp(command,"P6")==0)
		{
			PID_Pos_Cur.P= atof(data);
		}
		else if(strcmp(command,"I6")==0)
		{
			PID_Pos_Cur.I= atof(data);
		}
		else if(strcmp(command,"D6")==0)
		{
			PID_Pos_Cur.D= atof(data);
		}
				else if(strcmp(command,"P7")==0)
		{
			PID_Pos_Vel_Cur.P= atof(data);
		}
		else if(strcmp(command,"I7")==0)
		{
			PID_Pos_Vel_Cur.I= atof(data);
		}
		else if(strcmp(command,"D7")==0)
		{
			PID_Pos_Vel_Cur.D= atof(data);
		}
		else if(strcmp(command,"M0")==0)
		{
			mode= atof(data);
		}
		else if(strcmp(command,"C0")==0)
		{
			if(atof(data)>0.5f)
			{
				motor_calibration_requested=1;
			}
		}
		else if(strcmp(command,"L0")==0)
		{
			uq_limit= atof(data);
		}
		return data_flt;
}

void VOFA_RUN()
{
		if(mode<0)
		{
			setPhaseVoltage(0,0,zero_electric_angle_norm);
		}
		else if(mode==0)
		{
			PositionCloseloop(Pos_set);
		}
		else if(mode==1)
		{
			VelocityCloseloop(Velo_set);
		}
		else if(mode==2)
		{
			//velocityOpenloop(0.1);
			CurrentCloseloop(IQ_set,ID_set);
		}
		else if(mode==3)
		{
			Velocity_CurrentCloseloop(Velo_set);
		}
		else if(mode==4)
		{
			Position_CurrentCloseloop(Pos_set);
		}
		else if(mode==5)
		{
			Position_Velocity_CurrentCloseloop(Pos_set);
		}
		else if(mode==6)
		{
			velocityOpenloop(0.1);
		}
		
		
}
/* USER CODE END PFP */

/* USER CODE BEGIN 0 */
void System_Init()
{
		LOWPass_Init();
	  convert=vcc/shunt_resistor/adc_cpr/amp_gain;
}
/* USER CODE END 0 */

/**
  * @brief  The application entry point.
  * @retval int
  */
int main(void)
{

  /* MCU Configuration--------------------------------------------------------*/

  /* Reset of all peripherals, Initializes the Flash interface and the Systick. */
  HAL_Init();

  /* Configure the system clock */
  SystemClock_Config();

  /* Initialize all configured peripherals */
  MX_GPIO_Init();
  MX_DMA_Init();
  MX_ADC1_Init();
  MX_TIM1_Init();
  MX_USART1_UART_Init();
  MX_TIM3_Init();
  MX_FDCAN1_Init();
  MX_SPI1_Init();
  MX_TIM4_Init();
  /* USER CODE BEGIN 2 */
	HAL_ADCEx_Calibration_Start(&hadc1,ADC_SINGLE_ENDED);
	HAL_TIM_Base_Start(&htim1);
	HAL_TIM_PWM_Start(&htim1,TIM_CHANNEL_4);
	__HAL_TIM_SET_COMPARE(&htim1, TIM_CHANNEL_4, __HAL_TIM_GET_AUTORELOAD(&htim1) - 10);	
	HAL_ADCEx_InjectedStart_IT(&hadc1);
	ADC_Count_Caloffset();
	
	HAL_TIM_PWM_Start(&htim1,TIM_CHANNEL_1); //开启三个PWM通道输出
	HAL_TIM_PWM_Start(&htim1,TIM_CHANNEL_3);
	HAL_TIM_PWM_Start(&htim1,TIM_CHANNEL_2);
	
	HAL_TIMEx_PWMN_Start(&htim1,TIM_CHANNEL_1);
	HAL_TIMEx_PWMN_Start(&htim1,TIM_CHANNEL_2);
	HAL_TIMEx_PWMN_Start(&htim1,TIM_CHANNEL_3);

	HAL_TIM_Base_Start_IT(&htim3);
	HAL_TIM_Base_Start_IT(&htim4);
	MT6816_SPI_Signal_Init();
	CAN_Bridge_Init();
  /* USER CODE END 2 */

  /* Infinite loop */
  /* USER CODE BEGIN WHILE */
	System_Init();
#if YYT_DISABLE_OUTPUT
	Pos_set=0;
	Velo_set=0;
	IQ_set=0;
	ID_set=0;
	mode=-1;
	uq_limit=0;
	zero_electric_angle_norm=0;
	HAL_GPIO_WritePin(GPIOA,GPIO_PIN_4,GPIO_PIN_SET);
#elif YYT_SAFE_START
	Motor_init();
	PID_Pos_Set(50,27,0,6);
  PID_Cur_D_Set(7.5,30,0,6);
	PID_Cur_Q_Set(7.5,40,0,12);
	PID_Vel_Set(5,6.2,0,12);
	PID_Vel_Cur_Set(0.7,5.7,0,12);
	PID_Pos_Cur_Set(20,2,0,3);
	pole_pairs = MOTOR_POLE_PAIRS;
	Pos_set=0;
	Velo_set=0;
	IQ_set=0;
	ID_set=0;
	mode=-1;
	uq_limit=12;
	voltage_power_supply =12;
#if !MOTOR_AUTO_ELECTRIC_ZERO
	zero_electric_angle=MOTOR_ZERO_ELECTRIC_ANGLE;
#endif
	zero_electric_angle_norm=0;
	HAL_GPIO_WritePin(GPIOA,GPIO_PIN_4,GPIO_PIN_SET);
#else
	Motor_init();
	//4108 10 oomm parameter
	PID_Pos_Set(50,27,0,6);
  PID_Cur_D_Set(7.5,30,0,6);
	PID_Cur_Q_Set(7.5,40,0,12);
	PID_Vel_Set(5,6.2,0,12);
	PID_Vel_Cur_Set(0.7,5.7,0,12);
	PID_Pos_Cur_Set(20,2,0,3);
	pole_pairs = 11;
	Velo_set=6.28;
	mode=1;
	voltage_power_supply =12;
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

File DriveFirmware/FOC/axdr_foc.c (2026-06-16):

#include "axdr_foc.h"
#include "axdr_pid.h"

#define MATH_PI 3.14159265358979323846f
#define MATH_2PI 6.28318530717958647693f
#define NUM_OF_POLE_PAIRS 7.0f

//#define GI_D_KP (0.140358f)//1.0f Drag_IF_Mode
//#define GI_D_KI (706.3372224f)//24.0f  Drag_IF_Mode

//#define GI_Q_KP (0.1612076f)//1.0f Drag_IF_Mode
//#define GI_Q_KI (706.3372224f)//24.0f  Drag_IF_Mode
volatile float self_angle = 0,spi_pulse,mag_hudu, elec_hudu;
volatile float Id_ref = 0.0f, Iq_ref;
volatile float vel_cnt, vel_angle_0, vel_angle_1,vel,last_vel,low_alpha,vel_ref,vel_filt,last_vel_filt;
volatile float omega_vel, vel_delta_t = 0.0002f, xian_vel,xian_vel_filt,last_xian_vel,last_xian_vel_filt;
volatile float pos_cnt, pos_angle, last_pos_angle, pos_angle_360, pos_ref ,circle_count ,all_angle;

void FOC_Init(void)
{

}


//VF模式
void VF_RUN(void)
{
    //角度相关
    self_angle += 1;
    if (self_angle > 360)
        self_angle = 0;

    theta_angle = self_angle;
    tran_angle(theta_angle);                //角度转弧度
    sin_cos_val();                          //三角变换
    //坐标变换
    Vq = 10.0f;
    Vd = 0.0f;
    anti_park_transf();                     //旋转转静止坐标轴
    svpwm_calc();                           //SVPWM转三相

    TIM1->CCR1 = (uint16_t)(Tcmp1);
    TIM1->CCR2 = (uint16_t)(Tcmp2);
    TIM1->CCR3 = (uint16_t)(Tcmp3);
}

void IF_RUN(void)
{
    //角度相关
    self_angle += 0.5;
    if (self_angle > 360)
        self_angle = 0;

    theta_angle = self_angle;
    tran_angle(theta_angle);                //角度转弧度
    sin_cos_val();                          //三角变换

    //电流采样
    clark_transf();
    park_transf();
    //坐标变换
    Vq = PID_realize_q(1.0f,Iq);  //Vq为0.5的时候，Iq大概在1A左右
    //Vq = 0.5f;
    //Vd = PID_realize_d(0.0f, Id);
    Vd = 0.0f;
    //pid限幅
    float max_Vq = 0.5f;
    float max_Vd = 0.5f;
    if(Vq > max_Vq)
        Vq = max_Vq;
    if(Vq < -max_Vq)
        Vq = -max_Vq;
    if(Vd > max_Vd)
        Vd = max_Vd;
    if(Vd < -max_Vd)
        Vd = -max_Vd;
    //坐标变换
    anti_park_transf();                     //旋转转静止坐标轴
    svpwm_calc();                           //SVPWM转三相
    anti_park_transf();                     //旋转转静止坐标轴
    svpwm_calc();                           //SVPWM转三相

    TIM1->CCR1 = (uint16_t)(Tcmp1);
    TIM1->CCR2 = (uint16_t)(Tcmp2);
    TIM1->CCR3 = (uint16_t)(Tcmp3);
}
//motor.mag_hudu = (float)((MT6816_Get_AngleData() + 192) * MATH_2PI / 16384.0f);
//motor.elec_hudu = Mag_To_Electrical(motor.mag_hudu, NUM_OF_POLE_PAIRS);


//void Calibration_Zero(void)
//{
//    spi_pulse = MT6816_Get_AngleData();
//    //角度相关
//    self_angle += 1;
//    if (self_angle > 360)
//        self_angle = 0;
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

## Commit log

2026-06-16 feat: complete C3-to-YYT closed-loop control, MPU6050 filter, and PioPulse visualizer integration
    [4310云台电机拉马.step, PM3510拉马.step]
2026-06-17 chore: remove unused YYT design assets
    [4310云台电机拉马.step, PM3510拉马.step]
2026-06-17 docs: rename project to wheel-leg CAN controller
2026-06-17 fix: switch to CAN control and update IMU I2C pins to fix boot button conflict
    [LegConfig.h, main.cpp]
2026-06-18 Add safe CAN bringup with IMU status
2026-06-18 Add wheel I2C integration scaffold
2026-06-18 Add F103 wheel PWM coprocessor firmware
2026-06-18 CAN bridge + ID6 firmware reflash, diagnostic tools, factory data
    - Reflashed STM32 ID6 drive firmware (turing_CBU6_id6_6v.elf verified)
    - Updated can_bridge.c with DRIVE_ID-aware command routing and Bus-Off recovery
    - Updated main.cpp with CAN recovery, auto zero-hold, height hold, wheel I2C
    - Added diagnostic tools: read_status_safe.py, reset_esp32.py, run_zero_hold_id6.py,
    send_test_command.py, test_pulse_safe.py
    - Added i2c_line_diagnostic.cpp for I2C bus debugging
    - Added factory/ calibration data
    - Updated docs and platformio.ini with new build environments
    [Data.c, Motor.c, Motor.h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]
2026-06-18 feat: generalize zero hold control for all leg joint motors and fix compilation on Linux
    [can_bridge.c, main.cpp]
2026-06-18 feat: add dual wheel encoder support (AS5600/AS5600L) on ESP32-C3 and update compiled binaries
2026-06-18 docs: update README with dual-encoder and F103 control roles
2026-06-18 docs: document 6-PWM configuration for STM32F103 and SimpleFOC
2026-06-18 Upgrade STM32F103 wheel coprocessor to SimpleFOC 3-PWM drive
2026-06-18 Silence I2C requestFrom log warning spam when devices are offline
2026-06-18 Enable I2C in platformio.ini by default and update diagnostic delay
2026-06-18 Update motor directions and drive firmware IDs
2026-06-19 Add boot fixed pose hold tuning
    [main.cpp, read_status_safe.py]
2026-06-19 Update robot bring-up firmware and backups
    [4310云台电机拉马.step, PM3510拉马.step]
2026-06-27 Average YYT align samples

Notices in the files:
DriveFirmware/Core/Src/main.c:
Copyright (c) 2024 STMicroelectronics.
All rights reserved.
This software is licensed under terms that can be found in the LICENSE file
